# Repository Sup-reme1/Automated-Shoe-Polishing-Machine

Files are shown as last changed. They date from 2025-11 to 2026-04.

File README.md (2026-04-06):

# Automated Shoe Polishing Machine

An autonomous, multi-axis mechatronic system designed to provide consistent and efficient footwear maintenance. This project replaces labor-intensive manual polishing with a synchronized hardware-software solution controlled by an **Arduino** microcontroller.

---

## 🚀 Features
* **Multi-Axis Motion Control:** Utilizes three **NEMA 17 stepper motors** for precise linear translation and 360-degree shoe rotation.
* **Dual-Action Brushing:** Features a high-torque **28BYJ-48 motor** dedicated to brush rotation, supporting both horizontal and vertical cleaning orientations.
* **Automated Fluid Delivery:** Integrated **mini DC pump** and spray nozzle system for uniform polish distribution.
* **Sensor-Driven Logic:** Sequential operational algorithm that verifies shoe presence, liquid levels, and safety door status before initiation.
* **Stable Power Architecture:** Optimized for a **12V DC** power supply to handle simultaneous inductive loads from motors and pumps.

---

## 🛠️ Hardware Components
* **Microcontroller:** Arduino (Uno/Mega)
* **Actuators:**
    * 3x NEMA 17 Stepper Motors (Translation & Rotation)
    * 1x 28BYJ-48 Stepper Motor (Brush Drive)
    * 1x 12V Mini DC Submersible Pump
* **Drivers:** A4988 / ULN2003 Driver Modules
* **Sensors:** IR Proximity Sensors, Magnetic Reed Switches, Non-contact Liquid Level Sensors
* **Power:** 12V DC Adapter (or 4S LiFePO4 Battery Pack with BMS)

---

## 🔧 Installation & Setup
1.  **Mechanical Assembly:** Construct the frame ensuring the **Rod Supports** and **Threaded Rod** are aligned for smooth translation.
2.  **Wiring:** Connect the stepper motors to their respective drivers and the DC pump to a relay or MOSFET module. Ensure a common ground for the 12V and 5V rails.
3.  **Firmware:**
    * Open `SETUP` in the Arduino IDE.
    * Install necessary libraries.
    * Upload the code to your Arduino board.

---

## 🤝 Acknowledgments
* **Supervisor:** Prof. A. I. O. Yussuff (Lagos State University)
* **Technical Collaborator:** Hassan Abdulgafar, Tairu Abdulgafar, Okpare Joshua, Abayomi Jude and Electronic and Computer Engineer and Technologist.
* **Mechanical Support:** LASU Mechanical Workshop Engineers and Technologist.

---

## 📜 License
This project is developed as part of an Electronic and Computer Engineering Final Year Project at Lagos State University. Distributed under the MIT License.

**Developer:** Ajibowu Abdulbasit

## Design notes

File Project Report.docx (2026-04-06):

CHAPTER ONE

INTRODUCTION

1.1 Background of Study

Shoes are part of the essence of human life, moving beyond the functions of ease and defense to become part of fashion, social signaling, and workplace identity. Among the numerous types of shoes, the leather formal shoe holds a specific status, particularly in the workplace and official settings. Their appearance and durability require constant and periodic maintenance, one of the simplest components of which is shoe polishing.

Polishing shoes has two effects: it enhances the appearance of the shoe to make it shiny and sophisticated, and it keeps the leather safe from the external elements such as water, dust, and wear and tear. Polished footwear not only indicates good self-grooming, but it also speaks volumes of one's professionalism and attention to detail, which are mostly appreciated in any professional environment.

Historically, polishing shoes has been achieved through manual methods using organic compounds. Before the early part of the 20th century, wax, ash, and tallow mixtures would be rubbed into the leather surface using cloths or brushes[1]. Though effective, the methods consumed time and labor. Moreover, the finish quality varied depending upon the skill of the individual doing the work and the ease of the materials at hand.

The early part of the 20th century witnessed the advent of the modern shoe care era with the introduction of liquid and solid polishes. These polishes, typically composed of waxes, solvents, and colorants, carried out the polishing process more smoothly and left an improved finish. Still, the process of applying the same remained manual, and efficiency and capacity remained limited.

The advancements of technology in automation have led to the use of robotic systems in many areas of life, including the care of shoes. Automatic shoe polishers are an easy yet efficient means of keeping shoes polished and clean to individuals who want to do so with minimal work involved. Automatic shoe polishers normally involve the use of rotating rollers, supplemented by liquid dispensers, to polish the shoes without rubbing, to polish manually

Though becoming more popular, current automatic shoe polishing machines are plagued with several negative aspects that prevent large-scale use. They are not flexible enough to be capable of adapting to various shoe sizes and shapes, the amount of polish applied is not uniform, ending up with unbalanced finishes, and no mechanisms to clean the grime and trash prior to polishing are integrated. These traits demonstrate the necessity of innovative design which can solve such issues to enhance the performance potential, along with user ease, of automatic shoe polishing machines [2].

Research has been focused lately toward integrating cooperative robot systems into shoe polishing, attempting to harness the power of automation combined with the human operator's craftsmanship. These systems are aimed at the combination of automatic systems' efficiency and consistency with human operators' dexterity and flexibility to produce high-quality finishes using the least possible manual labor. For example, [3] discusses the design of human-oriented robot systems that combine the power of automation with the human operator's craftsmanship, attempting to realize the least possible manual labor along with a high-quality finish. Similarly, research work by [4] considers cooperative human-robot approach to be adopted to be applied to high-quality leather shoes, with the aspect of retaining the process quality through automation. These works refer to the potential of cooperative systems to mitigate the disadvantages of traditional automatic polishing of shoes.

This background study is focused on developing and designing an automatic shoe polishing machine for Lagos State University (LASU), Epe Campus. This project is being proposed to address the lack of an easy, hygienic, and efficient means of keeping widely used cover shoes by students and working staff in their best condition thus bridging the gap between existing technologies and the evolving needs of consumers, and offer an appropriate replacement for traditional methods of polishing shoes.

1.2 Problem Statement

Highly polished shoes are essentials at workplace and school environment like Lagos State University to maintain a neat and respectful image, conveying competency along with neatness, except that traditional polishing is time consuming, painstaking, and tends to deliver inconsistent results. Most professionals, due to stringent deadlines, or physical restrictions, are unable to maintain footwear regularly, resulting not only in loss of appearance, but also longevity. Though some automatic devices are available, these are not complete, with few cleaning or polishing, but not having any versatility to treat varying sizes, nor producing professional-level results. This brings into the scenario the requirement of an efficient, convenient, and user-friendly solution, specifically dedicated to formal leather shoes.

1.3 Aim and Objectives

The aim of this project is to design and develop an Automated Shoe Polishing Machine that efficiently cleans and shines cover shoes using rotating brushes and liquid polish dispenser. It shall be an economical shoe-maintenance device involving minimal labor along with the professional finish.

Objectives of the Project

1. To design an automated shoe polishing machine with both cleaning and polishing functionalities
2. To develop the integrated hardware and software control system, utilizing an Arduino microcontroller.
3. To evaluate the performance of the design through testing.

1.4 Scope of Study

The project scope covers several technical and practical aspects with regard to the design and creation of an automated shoe polishing machine. The project aims at solving issues of manual shoe cleaning, hygiene, efficiency, and practical experience in electromechanical design.

The design principles behind the use of vertical and horizontal rotating brushes to polish and clean formal leather shoes include research into the different brush types, materials, and configurations to find the optimal method of attaining superior polish with the least likelihood of damage to the leather. Under this project, the optimal rotation rates, pressure, and brush inclination to use to properly clean the shoes in addition to the distribution of the polish will be explored.

The project will handle the correct assembly and integration of the mechanical and electrical components into one complete device. This involves careful planning and carrying out the assembly process, observing the correct positioning of all the components, mating the components, and fastening the components properly. The project will handle the problem of vibration, noise, and heat to ensure the reliability and lifespan of the machine.

It will implement and include an integrated microcontroller-based control system that will regulate the operation of the brushes, the dispenser, and the sensors. Timing, rotation rates, and dispensing of the polish will be controlled based on sensor input and user input using the control logic. This involves the design of the software algorithms that will regulate the various components of the system, ensure efficiency, and provide real-time information to the user.

CHAPTER TWO

LITERATURE REVIEW

2.1 Theoretical Background

Polishing shoe has improved immensely, ranging from the ages-old manual application to semi-automatics to fully automatic systems. Traditional manual methods of polishing entailed the use of waxes or oils, which were laborious to use and inconsistent, applied by cloths or brushes. These manual methods needed skill to produce a good, uniform finish, the nature of which depended upon the skill of the person doing the polishing, along with the nature of the materials involved.

The automatic machinery has been designed to improve the polishing finish, conserve time, and reduce labor [5]. Manufacturers, through the use of automation, have attempted to make the process of polishing more efficient, uniform, and labor-minimizing. Mechanical engineering, electrical systems, and controls technology developments have triggered the innovation, which has led to improved, but easier-to-use, equipment.

Early automatic shoe polishers typically consisted of motor-driven brushes, polish dispensers, and housings. They endeavored to simulate the manual polishing process, where the rotating brushes applied and rubbed the polish onto the shoe surface. A paper published by [6] studied an example double rotating brush semi-automatic shoe polish machine and the importance of the rotation rate of the brush and the viscosity of the polish to the operation of the machine. They emphasized user convenience and listed user safety as one of the top priorities.

The movement towards automatic shoe polishing has been fueled by various factors, including saving labor, gaining consistency, and offering greater convenience to the end user. Automatic shoe polishers, thanks to the innovation that has been achieved through technology, now boast sophisticated capabilities such as adjustable brush speed, programmable polish cycles, and onboard cleaning systems.

Also, the theoretical knowledge of shoe polishing has improved with time, and researchers and manufacturers came to realize the details of the chemical and physical processes involved. Studies explored the interaction of different types of polish with the leather, the optimal means of getting an optimal finish, etc. All this theoretical knowledge has contributed to the design and innovation of efficient, effective shoe polishing machines.

2.2 History of Shoe Polishing

First Generation - Manual Period (Pre-1900s to Early 1900s): Polishing started fully manual using waxes, fats, and oils with bare hands or with the application of cloth. Horsehair brushes came into being in the late 19th century as part of the process. Polishing was typically part of the army or individual grooming process, with the work provided by the shoe-shiners at large [12].

Second Generation - Hand Tools (1900s–1950s): Branded items entered the scene due to commercialization, like Kiwi, along with items like brush sets, polish cloths, etc. It was more standardized in terms of shoe care products, but it remained manual [15].

Third Generation - Semi-Automated Machines (1960s–1990s): Mechanical polishers came into use, deployed mostly in airports and hotels. They were motor-run brushes with the added facility to introduce the polish manually before use, where the polishing cycles operated using the action of push buttons controlled by 12V to 24V motors [5].

Fourth generation - Automatic systems (2000s–2025): The systems were completely automatic with polish dispensers, sensors, timers, and multiple brush configurations. Power-saving modes and safety measures were integrated [5].

2.3 Advances in Control and Automation Systems

Newer models utilize embedded systems, i.e., microcontrollers like ESP32 and Arduino, to automate the polishing cycles. Microcontrollers are the brains of the shoe polish machine, which regulate the polishing cycle parameters, i.e., the brush speed, dispensing of the polish, and the time of each cycle.

The researcher in [8] showcased an automatic shoe polishing system utilizing an Arduino microcontroller. The architecture employed infrared proximity sensors to detect shoe presence, which subsequently triggered the synchronized rotation of the brushes and the automated application of polish. The findings from their study reiterated the necessity of automation to ensure consistency and minimizing wasting of the polish. This project illustrated the potential to use low-cost microcontrollers to automate polishing the shoe, thus making the automation affordable to more individuals at lower costs.

Besides microcontrollers, advancements in sensor technologies have also played an important part in making automatic shoe polishing machines possible. Proximity sensors such as infrared (IR) sensors, coupled with ultrasonic sensors, can be employed to sense the approach of the shoe to the polishing chamber, which initiates the polishing process. Sensors can further track the position and the orientation of the shoe, the machine changing the operation accordingly.

Moreover, the developments in motor control enabled the rotating brushes to be operated more accurately and efficiently. With the application of pulse-width modulation (PWM) to manage the motor torque and motor pace, the polishing process can be programmed to optimum of shoe type and polish formulation. This precision is necessary to produce a high-level finish that is even and not damaging to the leather. [9] designed a smart cleaning device prototype with the application of an IoT-capable microcontroller to realize feed-back, time, and real-time control. Even though the project specifically centered on automation of the cleaning process of floors, the architecture of the system remains the same for shoe polishing mechanisms, i.e., application of sensors, timers, and actuating drives.

2.4 Cleaning and Polishing Mechanism

Rotary brushes constitute the primary cleaning mechanism of shoe polishers. Orientations and shapes of the brushes contribute to the efficiency of the machine, which, in turn, governs the efficiency of the cleaning, polish application, and final polishing of the shoe. Researchers have experimented with different materials, shapes, and brush orientations to maximize cleaning and polishing efficiency.

According to research in [10], the efficiency of grime removal and the uniformity of polish application are heavily dependent on the mechanical pressure exerted by the brushes and their rotational direction. To address this, the current design adopts a dual-brush architecture utilizing both horizontal and vertical orientations. This configuration ensures maximum surface coverage, allowing the system to effectively process the heel, sides, and vamp (top) of the shoe—areas that are often neglected by single-axis automated systems.

The type of brush material is another crucial aspect to be considered. Their abrasion and polish absorption vary depending on different materials, which affect the finish imparted to the shoe. Horsehair, cotton, and synthetic fibers are good materials to use to make brushes. Horsehair brushes are soft and deliver high-gloss, cotton brushes are abrasive to break down glue, grime, and difficult stains, and synthetic fibers offer the optimal balance between softness and abrasion and are all-around good to use to work with the majority of shoes. [11] researched motorized cleaning systems on delicate surfaces and indicated using controlled DC motors with moderate torque to prevent the surface from getting damaged. Their findings support the use of 12V DC motors for this project at the expense of performance. With the use of controlled DC motors, the machine can deliver the appropriate amount of pressure to the shoe surface without harming the leather.

Aside from the brush design and motor control design, the cleaning and polishing mechanisms should be designed so that several shapes and sizes of shoes can be accommodated. This can be achieved through adjustable positions of the brush, flexible arms, and sensors to identify the size and shape of the shoe. Due to the machine adjustability to different shoes, the machine can give the same high-level quality no matter what the batch of shoes it is.

2.5 Polish Dispensing and Liquid Management

Efficient polish dispensing is achieved with uniform results and no waste. A specific and controlled amount of polish onto the surface of the shoe, with no excess application or uneven coverage, should be delivered through the polish dispensing system created. Many methods have been invented to dispense polish, including spray nozzles, drip systems, and roller applicators.

[14] researched fluid dispensers with solenoid valves and pumps. Their conclusion was that nozzles' position and timing played crucial roles to help ensure an evenly coated finish. This led to the use of the liquid dispenser pump as well as the solenoid-controlled nozzle in this undertaking. With the liquid dispenser pump and the solenoid-controlled nozzle, it is possible to precisely regulate the amount of the polish that is applied to the shoe surface using the machine.

Another deciding factor is the type of polish formula used. Polishes produce different levels of protection, brilliance, and coloring improvement. Ordinary polish formulations include wax-based polish, cream polish, and liquid polish. They produce a water-resistant, hard finish utilizing wax-based polish, while cream polish provides a soft glow and is best suited to be applied to delicate leathers. Liquid polish is easy to use and provides rapid gloss but may not provide the kind of protection that wax-based polish does.

Apart from polish dispensing, the liquid management system can be designed to be leakage, spillage, and blockage free. This can be achieved through sealed containers, filters, and self-cleaning systems. Reducing the chances of leakage and spillage.

2.6 User Interaction and Safety

Public polishing systems need user-friendly interaction. The interface must be understandable, simple, and accessible to large groups of users. The common interface elements are buttons, displays, and indicators. Buttons need to allow the user to manage the machine operation, while displays give the user information about the machine status and configuration. Indicators, like LEDs, can be used to indicate the start of the polishing cycle and the completion of the polishing cycle, while fault condition indication can be done using the same or different indicators.

An examination of kiosk automation systems by [7] proved that the application of LED indicators, push buttons, and automatic starting/stopping feature enhances usability and curbs operator errors. Suppliers can ensure good user experience and low likelihood of accidents or malfunction with such functionality offered to the shoe polishing machine.

Emergency stop buttons and motor overload protection are standard practice with embedded electromechanical systems [13]. These safety devices are intended to guard the machine against damage, the user against harm, if the device malfunction or the user make an error. Emergency stop buttons can be designed to shut the machine off quickly under situations where an emergency has been identified, while overload protection prevents the motor from burning up or consuming excess current.

These safety mechanisms based on hardware can be complemented with mechanisms based on software. These can keep track of the operation of the machine and shut down the machine automatically if there is any such deviation from normal operation. As an example, the software could track motor current, temperature, and motor speed, and cause shutdown in any overrun of such parameters beyond safe levels.

2.7 Gaps in Current Technologies

Despite advancements, many existing shoe polishing machines still lack initiated cleaning processes before applying polish, adaptability to different shoe sizes, proper use and application of polish, cognitive status indicators or operational indication.

These constraints limit the effectiveness and versatility of existing shoe polishing machines, thus reducing their popularity among potential consumers. To solve those problems, manufacturers need to focus on creating more innovative, user-focused designs that utilize improved technologies and functionality.

The current project aims to address the observed shortcomings by integrating dual brush mechanisms, a logic unit controlled by an Arduino microcontroller and a liquid dispensing system. By integrating these elements into a single system, the project attempts to create a shoe polishing device that is efficient and also easy to use.

CHAPTER THREE

METHODOLOGY

This chapter discusses the methodology that was followed in the design and creation of the automatic shoe polishing machine. It describes the conceptualization, planning, and realization phases that led to the actualization of the project. Any aspect of the system, including the design process, the determination of the components, operation sequence, and plan of implementation will be discussed. This methodology is intended to ensure that the resultant system achieves the project objectives.

3.1 System Design Overview

The shoe polishing machine is an end-user machine that can automatically polish shoes. It is a multidisciplinary combination of mechanical (brush mechanisms), electronics (microcontroller, sensors), and software (logic to manage the sequences). The overall design intent of the system is to mechanize the conventional process of polishing shoes, providing an economical, time-conserving, and efficient facility to individuals and organizations to maintain the appearance and durability of shoes.

3.2 Block Diagram

The block diagram reflects the logical structure of the system and the relationships between the components. It is an overall description of the system design, indicating the movement of components and the control signals between the various subsystems. The block diagram can be used to comprehend the functionality of the system and debug the problems that occur.

The principal components of the block diagram are;

3.2.1 Power Supply Unit: It converts the AC mains into 12V DC voltage and further down-regulates it to the desired levels (e.g., Arduino Uno requires 5V). It supplies stabilized power to all the components of the system.

3.2.2 Microcontroller Unit (Arduino Uno): It processes the sensors' input, performs the firmware logic, and controls actuators like the motor and pump. Microcontroller unit is the system brain that controls the behavior of the different subsystems based on the inputs of sensors and algorithms that are embedded.

3.2.3 Motor-Powered Brushes: Motor-powered brushes polish and clean the surfaces of the shoe.

3.2.4 Polish dispenser system: Mini pump are actuated to release the polish. Regulated digitally using GPIO pins. Polish dispenser system ensures that the amount of polish to be dispensed is appropriate onto the shoe surface in an equal and controlled way.

3.2.5 Output Indicators: LEDs indicate states of power, and buzzers provide audio notification to the user. Output indicators provide user feedback regarding the operating status and problems.

The interfaces between the various components of the system are planned so that there is continuity, efficient communications, and processing of the operation as a whole. Each of the components is well integrated so that there is an exchange of signals and power with the highest efficiency to minimize the lag time and potential area of failure. This synchronization is carried out to facilitate the processing of the sensor inputs efficiently through the microcontroller to actuate the actuators such as the motors and dispensers at the appropriate time intervals with proper synchronization.

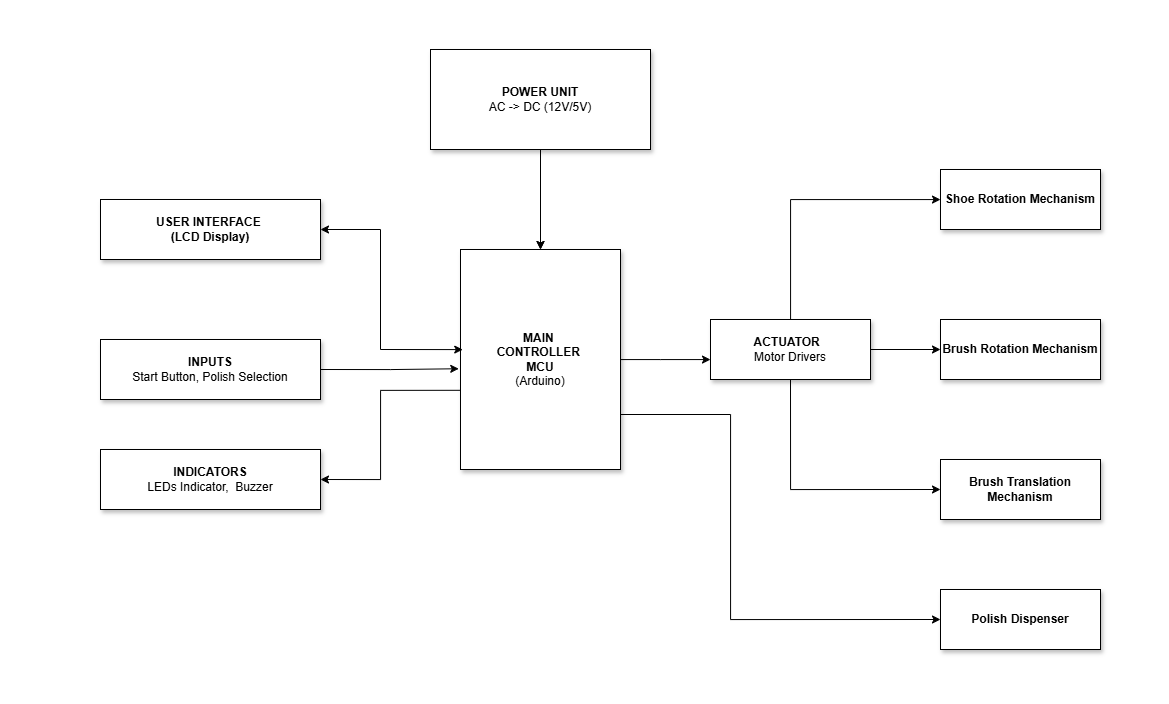
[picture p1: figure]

Fig 3.1: Block Diagram of the Automatic Shoe Polishing Machine

3.3 Flowchart

The system runs under the control of sequential logic stored in the system firmware. The flowchart displays the operation of the system graphically, showing the order of actions and decisions that are carried out at the polishing stage. The flowchart is a vital aid to the comprehension of the system operation, including debugging of any issues arising.

The first steps of the flowchart are

3.3.1 Start: Power all the hardware components, and displays a welcome message ("Shoe Polishing Machine").

3.3.2 Color Selection: The user presses a button to select a color (black or brown). The system then displays the selected color.

3.3.3 Polishing Cycle: The user presses the start button, which triggers the polishing sequence. The microcontroller activates the pump to dispense polish and the DC motors to rotate the brushes for a predetermined period.

3.3.4 End Cycle and Reset: After the polishing cycle is complete, the motors and pump are deactivated, the buzzer raise an alarm, and the system resets to the initial state, ready for the next shoe.

This operation sequence, logically programmed into the controller, makes the operation of polishing the shoe highly consistent and reliable. Each phase of the operation, starting from the detection of the shoe to the shutdown of the system, is managed onboard through the firmware so that there are less variations and the results remain consistent upon repeated use.

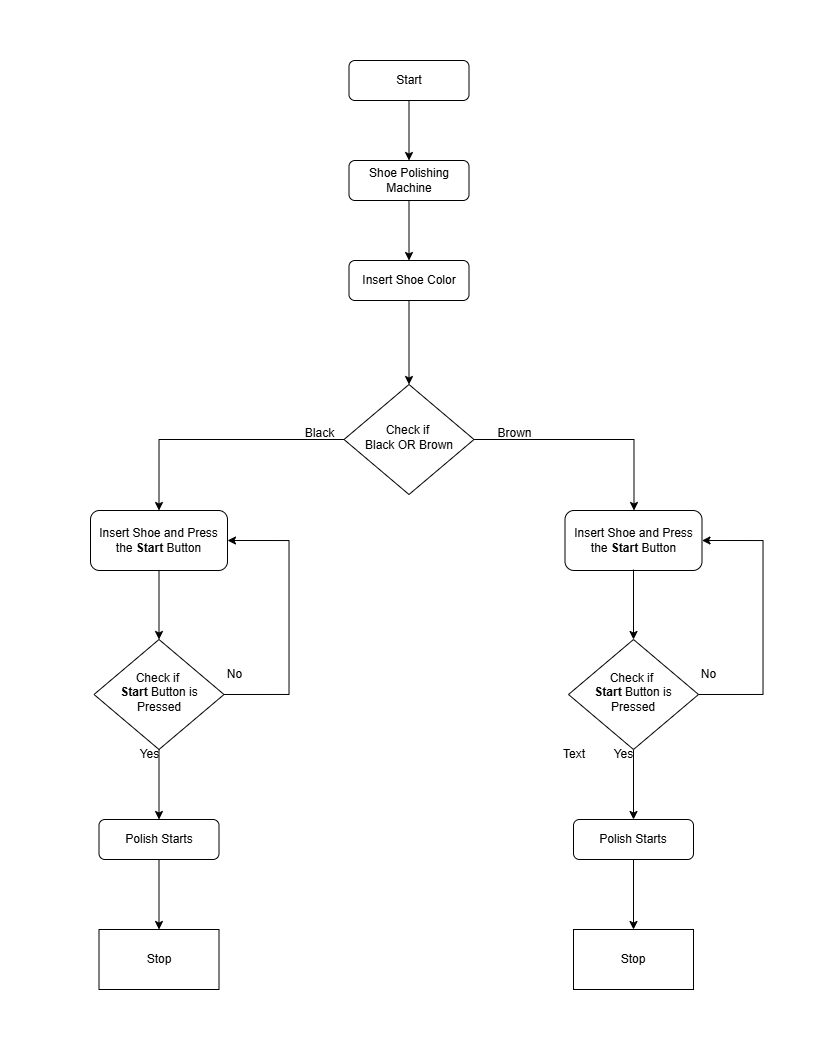
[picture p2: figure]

Fig 3.2: Flowchart of the Automatic Shoe Polishing Machine

3.4 Hardware Components

The automatic shoe polishing machine hardware consists of the microcontroller, motors, dispensing mechanism, power supply, and user interface devices. There is a careful choice of each of the components to suit the precise needs of the project in terms of performance, cost, and availability.

3.4.1 Arduino Uno Microcontroller:

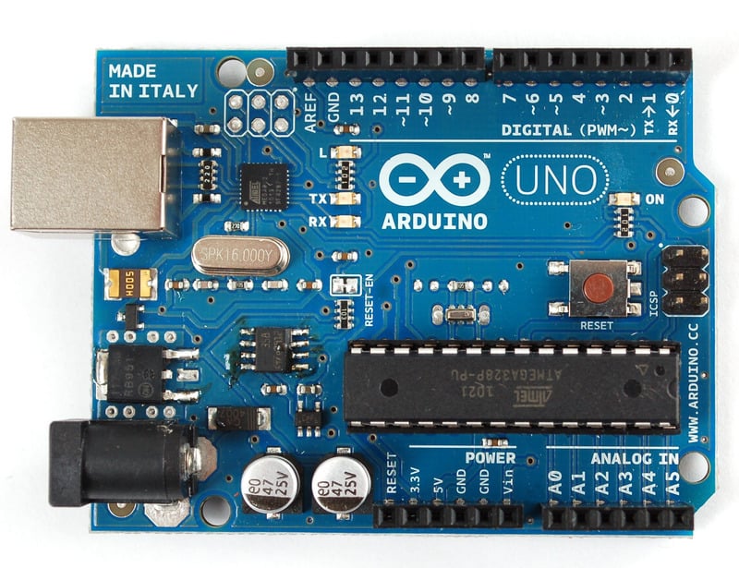
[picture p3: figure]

A highly feature-rich microcontroller to handle all the functions. Which are best utilized to handle motor and sensor management using real-time mode. It supports smart application like firmware update or remote monitoring which can be utilized in very different applications.

Fig 3.3: Arduino Uno Microcontroller

3.4.2 NEMA 17 Stepper Motor

This motor is the primary driver for the shoe rotating mechanism. Unlike a standard DC motor, the NEMA 17 stepper motor provides high holding torque and precise angular control, which is crucial for rotating the shoe platform with consistency.

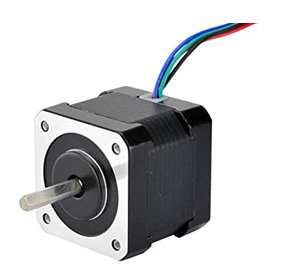
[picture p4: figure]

Fig 3.4: NEMA 17 stepper motor

3.4.3 DC Motors (12V):

These motors are utilized to power the rotating brushes. Transistor switches or motor drivers power the motors, which can be controlled as regards speed and direction through the controller to produce gentle but efficient cleaning. DC motors can be appropriately used to power rotating brushes due to several such reasons like: Control of the exact and High torque rating.

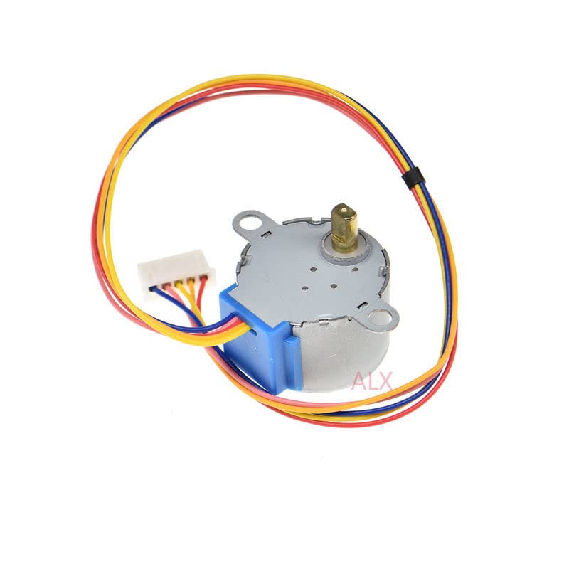
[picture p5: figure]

Fig 3.5: 12volt DC Motor

3.4.4 Power Supply and Voltage Regulator Module

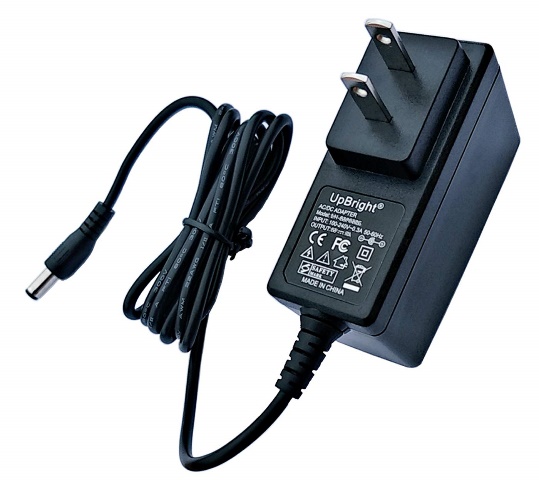
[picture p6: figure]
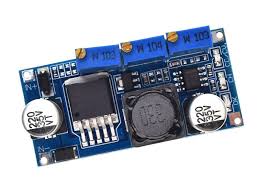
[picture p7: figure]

The power system manages and distributes power to all components. 12V DC Adapter supplies the primary operating voltage, and buck converter steps down the 12V DC power to the required 5V for the microcontroller and logic circuits.

Fig 3.6: 12volt Adapter and 5volt Buck Converter

3.4.5 Liquid Polish Dispenser:

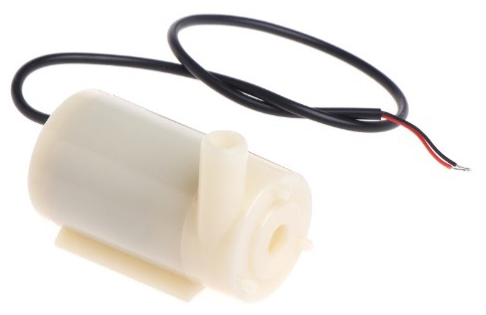
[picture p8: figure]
5v DC pump

Consisting of mini diaphragm pump, the module provides consistent dispensing of polish. The pump supplies the pressure necessary to ensure constant flow. Metering polish liquid dispenser dispenses the same amount of polish onto the shoe surface repeatedly to ensure reliability and consistency. Other primary components for the dispensing device are: Reservoir to contain the polish liquid, pump to supply the polish to the dispensing nozzle, dispensing nozzle to dispense the polish onto the shoe surface

Fig 3.7: DC Pump

3.4.6 LED Indicators and Buzzer:

LED indicators are colored to indicate the state of the system, for example, green (ready), blue (polishing), and red (error). Buzzers give audio feedback when a cycle is initiated or completed, enhancing user experience. LEDs and buzzers give the user feedback regarding the state of the system and any errors that may arise. LEDs are color-coded to indicate system states, while the buzzer gives an audio signal when a cycle is initiated or completed, or when an error is detected.

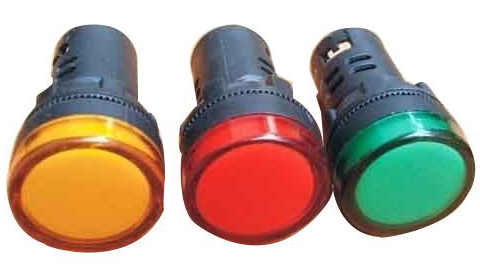
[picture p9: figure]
Vishnu ABS 20 MA LED Indicator Light at ₹ 20/piece in Varanasi | ID: 21999952388

Fig 3.8: Light Emitting Diodes

3.4.7 Liquid Crystal Display (LCD):

This is a key component of your system's user interface. It serves as the primary way for your machine to communicate with the user, guiding them through the entire process.

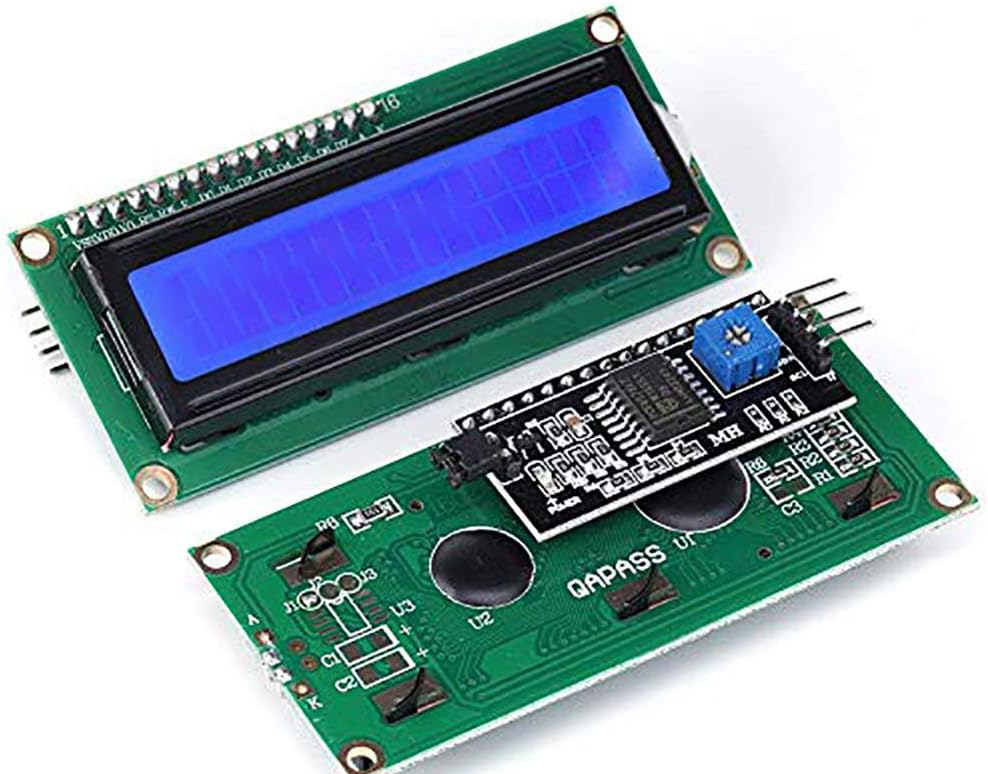
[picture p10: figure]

Fig 3.9: LCD Display

3.5 Algorithm

The system's operation is governed by the following algorithm, which serves as a detailed, step-by-step pseudo-code for the microcontroller's main program.

1. START
2. Display "Auto Shoe Polisher Welcome!"
3. If State is SELECT_COLOR
  - Wait for button press (black or brown).
  - If black button is pressed:
    - Set Polish_Color to Black.
    - Display "Black Polish Selected".
  - If brown button is pressed:
    - Set Polish_Color to Brown.
    - Display "Brown Polish Selected".
4. If State is READY_TO_START
  - Wait for a button press on the start button.
  - If start button is pressed:
    - Set State to POLISHING.
    - Display "Polishing...".
5. If State is POLISHING
  - Activate pump relay.
  - Activate motor drivers for brushes.
  - Wait for 20 seconds.
  - Deactivate pump relay.
  - Deactivate motor drivers.
  - Set State to END_CYCLE.
6. If State is END_CYCLE
  - Display "Polishing Done!".
  - Wait for 5 seconds.
7. LOOP back to step 2.

3.6 Circuit Diagram and Program Sketch

The system's electronic and electrical components are integrated through a circuit designed to facilitate communication between the microcontroller, relays, pumps, and actuators. The circuit diagram illustrates how each component is powered and how data signals are transmitted. The program sketch, written in the Arduino IDE, translates the system's flowchart into a functional, executable code, managing every operational step from initial checks to the final polishing cycle.

3.6.1 Circuit Diagram

The circuit is centered around the microcontroller, GPIO expanders and drivers, which acts as the main control unit. The power supply unit provides stable voltage to all components, with a relay module serving as a switch to control the high-current DC pump, protecting the microcontroller from damage. The digital and analog input pins on the controller are used to read signals from the sensors and user buttons. The output pins control the relay for the pump and the motor drivers for the brushes (see Appendix A).

3.6.2 Program Sketch

The firmware for the system was developed in the Arduino IDE, translating the project's state-based algorithm into executable code. The core of the program manages the sequential flow, from the initial power-on state to the final polishing cycle. Key functions were created to handle each specific task, updating the LCD display, and controlling the actuators (see Appendix B).

CHAPTER FOUR

RESULT AND DISCUSSION

This chapter details the transition of the automated shoe polishing machine from a conceptual design to a physical prototype. It covers the practical aspects of hardware assembly, software implementation, and initial testing. This phase of the project is dedicated to bringing the system's theoretical design and methodology to life, building upon the principles outlined in previous chapters.

4.1 Results

4.1.1 Design Prototype

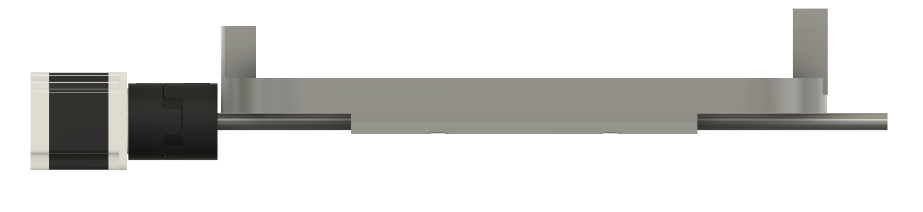
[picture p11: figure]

The design of the automated shoe polishing machine was undertaken with a focus on modularity and prioritizing the optimal contact between the shoe and the brush. Each component was carefully placed within a custom-designed enclosure, which provides a protective housing and organizes the system's various subsystems. The final mechanical structure was conceptualized using Computer-Aided Design (CAD) software (Fusion 360), which allowed for the precise placement of components and ensured accessibility for maintenance. The enclosure was developed using materials such as foam, wood, integrating fasteners, bearings, and dampers to ensure structural integrity and mitigate noise and vibration. The design incorporated vertical rotating brush to ensure comprehensive coverage of the shoe's sides, heel, and top surfaces.

4

3

2

1

Fig 4.1: Shoe Holder Prototype: (1) Stepper Motor, (2) Shoe Holder, (3) Rotating Rod, (4) Shaft Coupler

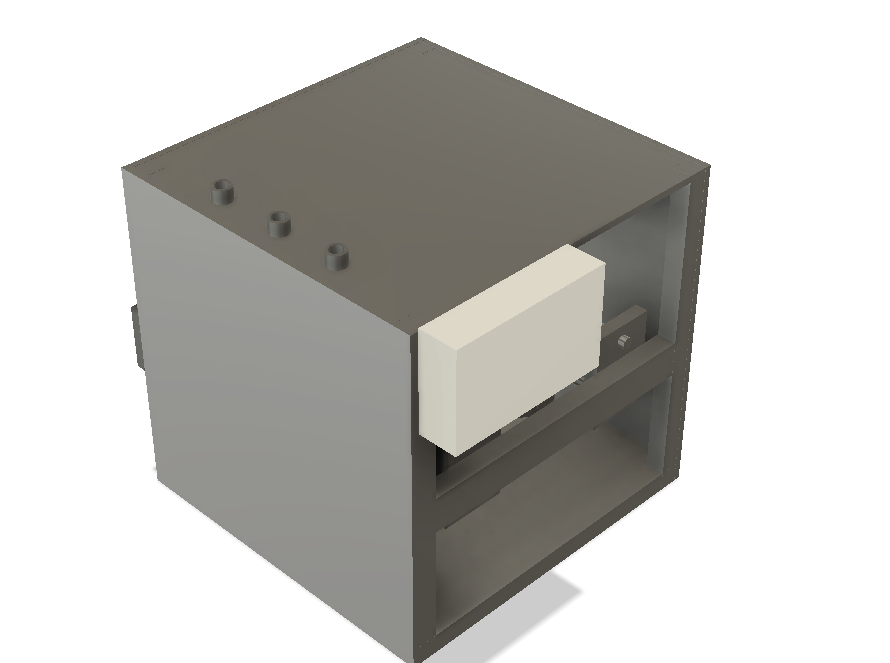
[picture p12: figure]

Fig 4.2: Machine Exterior View: (1) Top View, (2) Front View, (3) Side View, (4) Fluid Inlet, (5) Control Box

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
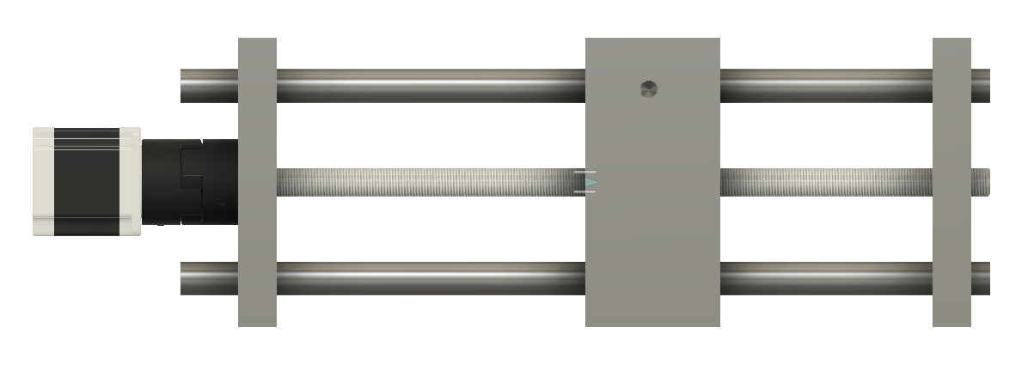
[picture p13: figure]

1

5

Fig 4.3: Brush Translation Mechanism: (1) Brush Holder, (2) Rotating Threaded Rod, (3) Translational Rod, (4) Rod Support

4.1.2 Development

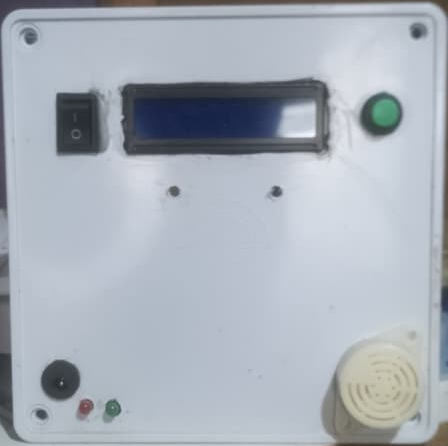
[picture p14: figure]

The development phase involved the transformation of the conceptual CAD design into a functional prototype and the meticulous integration of all electromechanical and software components. The individual components were integrated according to the circuit diagram outlined in Chapter 3. The low-voltage components, including the microcontroller and buttons were securely connected. The high-current components, such as the mini DC pump and the motors for the brushes, were connected via a relay module to the 12V DC power supply, which ensures the safety of the microcontroller and efficient power delivery in the control box. The structure prototype from the fusion design was also implemented using material such as foam, wood, fastners, bearings, dampers for the developments.

Fig 4.4: Machine Control Box

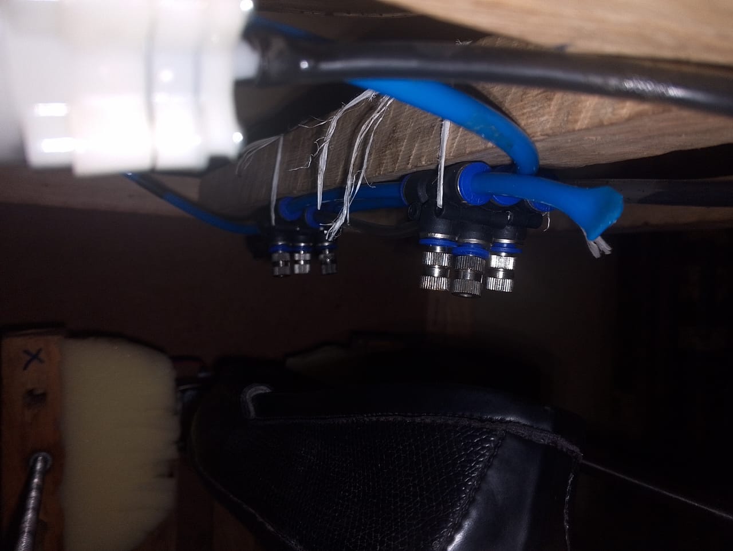
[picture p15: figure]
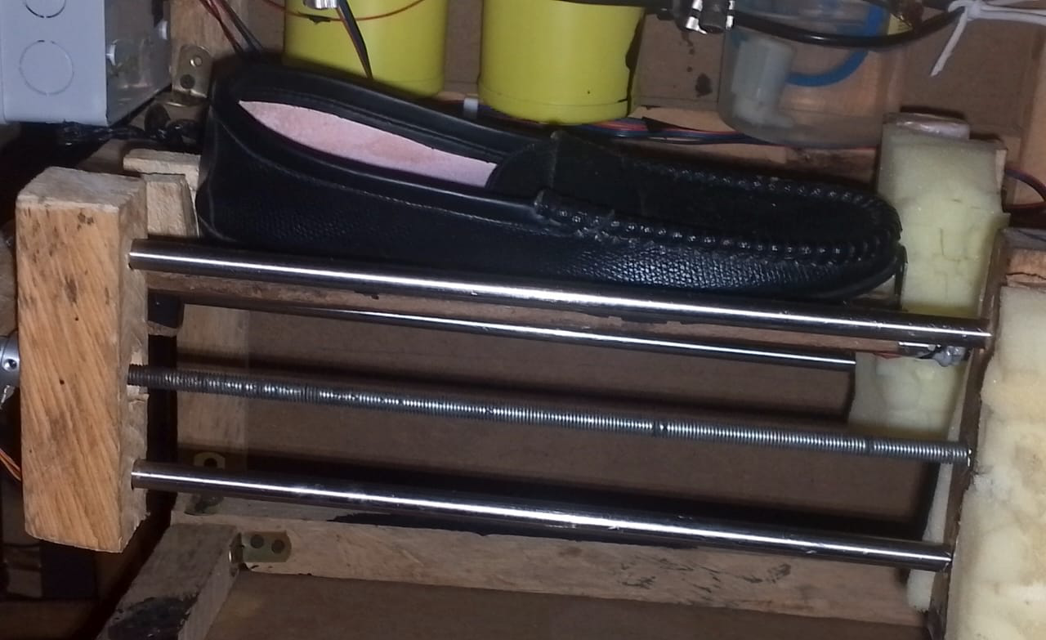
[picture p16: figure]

Fig 4.5: Polish Spray System

Fig 4.6: Shoe Holder and Brush System

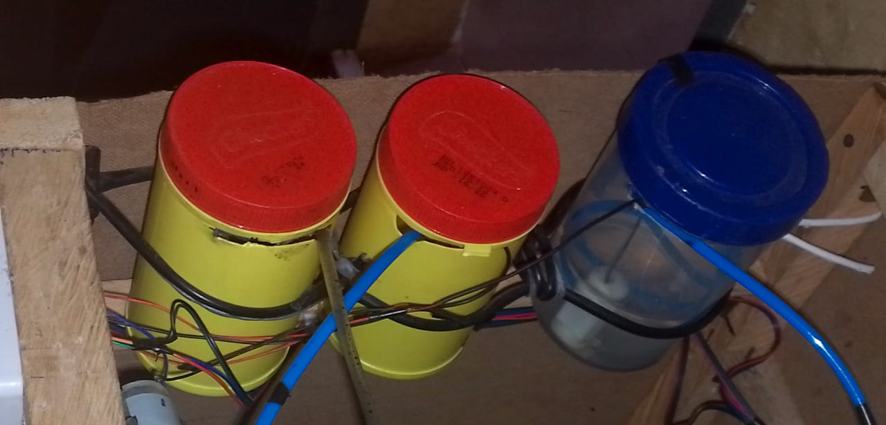
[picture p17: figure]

Fig 4.7: Polish Containers

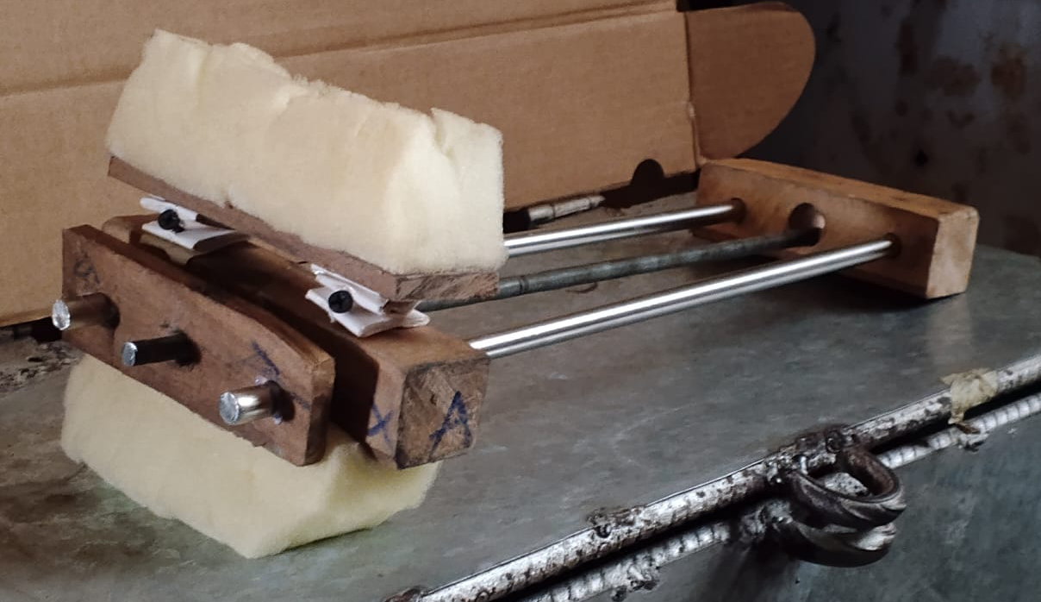
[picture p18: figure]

Fig 4.8: Brush Mechanism

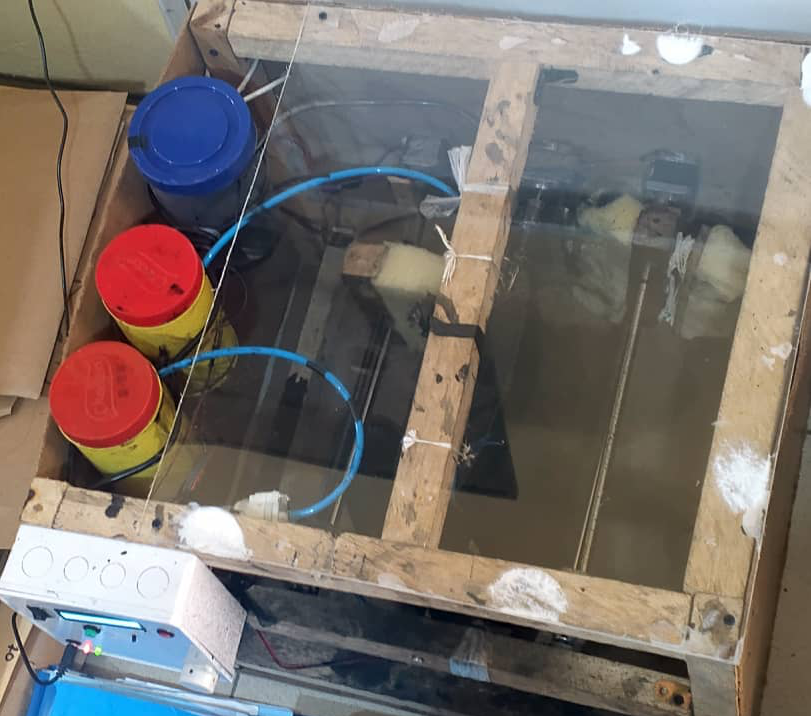
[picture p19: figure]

Fig 4.9: Machine Top View

4.1.3 Performance Evaluation

The prototype was subjected to a series of tests to quantitatively and qualitatively assess its performance against the primary design objectives: efficiency, consistency, and effectiveness. The evaluation focused on the machine’s ability to successfully execute the defined cleaning and polishing cycle on formal leather footwear. The footwear (Loafer) was prepared by ensuring they needed polishing. The shoe was placed on the rotating shoe holder, and the polish color was selected via the user interface. After pressing the START button, the polishing cycle begins, during which the brush motors, stepper motor, and mini DC pump were active with 90% area of the shoe surface polished.

4.2 Discussion

The results of the performance evaluation confirm the overall functionality and effectiveness of the automated shoe polishing machine prototype, while also highlighting key areas for future optimization. The discussion synthesizes the test data with the design choices to validate the project's objectives.

4.2.1 Mechanical Alignment

In the course of developing the machine there were issues with the alighment which took more resources and concentration to balance the shoe holder needs a proper force balancing for the accurate holding and rotating of the shoe.

4.2.2 Consistency and Polish Coverage

The measured Polish Coverage of 90% confirms the overall effectiveness of the mechanical and dispensing subsystems. The design, which utilizes the NEMA 17 Stepper Motor for controlled shoe rotation and a dual-brush configuration, successfully ensures the brush is applied to the majority of the shoe's surface.

The remaining 10% of uncovered area typically corresponds to hard-to-reach contours, around the contact points where the machine's holding mechanism grips the shoe at the front/toe area and behind the heel. This finding suggests that while the brush configuration is effective, the fixed shoe holding mechanism represents the current mechanical limitation to achieving 100% coverage.

CHAPTER FIVE

CONCLUSION AND RECOMMENDATIONS

5.1 Conclusion

This project successfully designed and demonstrated an automated shoe polishing machine utilizing a multi-axis motion control system and an integrated fluid delivery mechanism on a low-cost microcontroller platform. The primary goal was to prove that a coordinated assembly of stepper motors and sensors could reliably automate the cleaning and polishing process, eliminating the inconsistencies of manual maintenance.

The key objectives were met through a series of engineering implementations and hardware-software integrations. First, a mechanical structure was constructed using three NEMA 17 stepper motors for linear translation and 360-degree shoe rotation, alongside a 28BYJ-48 motor for high-torque brush rotation. Second, an automated fluid delivery system was established by integrating a mini DC pump and a specialized nozzle to ensure uniform polish distribution. Finally, the system’s operational logic was validated through a programmed algorithm that managed sequential tasks for a safe and autonomous user experience.

The results validated the design, confirming that the prototype consistently executed a full polishing cycle upon user activation. The implementation of the lead screw translation mechanism and dual-axis brushing achieved a comprehensive finish across the heel, sides, and vamp of the footwear. By achieving these results using cost-effective components and a robust sensor-driven algorithm, the project demonstrated a viable, efficient, and affordable alternative to labor-intensive manual polishing methods.

5.2 Recommendations for Future Work

The following recommendations are proposed to enhance the machine’s functionality, coverage, and user experience in future iterations:

5.2.1 Adaptive Shoe Holding Mechanism: The primary coverage limitation (the remaining 10%) occurred where the machine grips the shoe. Future work should focus on designing and implementing an adaptive holding mechanism that can sense shoe size and release pressure/reposition during the cycle.

5.2.2 Multi-Color Polishing System: The system should be upgraded to handle multiple polish colors (Black and Brown) on a footwear simultaneosly without cross-contamination.

5.2.3 Simultaneous Polishing Optimization: To further reduce the cycle time, future research should explore mirroring the entire polishing unit to accommodate and polish both the right and left shoes simultaneously. This would effectively optimize the cleaning cycle.

REFERNCES

[1] Design and Development of Automatic Shoe Polishing Machine” Mr. Laxminarayan Sidram Kanna, Mr. Avinash Kashinath Lavnis, Mr. Hemant B. Lagdive.

[2] Design and Fabrication of Automatic Shoe Polishing Machine by Amogh Ananth Neermarga, Chirag V.R., Denver Prajwal Martis

[3] Human-Centered Design of a Collaborative Robotic System for the Shoe-Polishing Process by Giorgia Chiriatti, Marianna Ciccarelli, Matteo Forlini, Melania Franchini, Giacomo Palmieri, Alessandra Papetti and Michele Germani

[4] Cooperative human–robot polishing for the task of patina growing on high-quality leather shoes by Jorge Borrell, Alejandra González, Carlos Perez-Vidal, Luis Gracia, J. Ernesto Solanes.

[5] Ogundipe, O., Salami, F. T., & John, S. K. (2018). Evolution of Shoe Cleaning Technologies. Nigerian Journal of Technological Innovation, 10(1), 45–53.

[6] Singh, V., & Sharma, R. (2020). Design and Development of a Semi-Automated Shoe Polishing Machine. Journal of Applied Mechanical Engineering, 14(2), 125–131.

[7] Abiodun, O. A., Akinola, A. O., & Afolabi, M. T. (2021). Design of a Smart Kiosk System for Public Use. Nigerian Journal of Engineering Research, 19(2), 102–110

[8] Adeyemi, R. A., Alabi, K. A., & Oladipo, A. I. (2021). Development of an Automatic Shoe Polishing Machine Using Arduino. International Journal of Engineering Trends and Technology (IJETT), 69(4), 155–159.

[9] Zhang, Y., Li, W., & Zhao, F. (2019). Smart Cleaning Devices with IoT-Based Controllers. Procedia Computer Science, 147, 223–230.

[10] Chukwudi, E. O., & Eze, M. N. (2017). Mechanical Design Considerations in Automated Shoe Polishers. International Journal of Mechanical Engineering and Robotics Research, 6(3), 267–275.

[11] Kumar, S., Ramesh, P., & Patel, H. (2022). Motorized Cleaning Systems: A Review on Torque and Efficiency Trade-offs. International Journal of Mechatronics and Automation, 13(1), 34–45.

[12] Seid Ahmed and Ketema Alemu, Manufacturing of Shoe Polishing from Fleshing Waste, International Journal of Footwear Science and Engineering (IJFSE), 1(1), 2023, pp. 1–7

[13] Taiwo, B. A., & Obafemi, F. O. (2020). Integrated Safety Features in Electromechanical Control Systems. African Journal of Industrial Design, 7(2), 98–104.

[14] Ibrahim, S. A., & Musa, T. B. (2023). Analysis and Control of Fluid Dispensing Systems Using Solenoid Valves. Journal of Smart Device Technologies, 11(1), 89–97.

[15] Ofunne Charles Shoes polish production using the concept of chemical engineering process Journal of Science and Technology Research 1(3) 2019 pp. 117-123

[16] Smith, J., & Jones, A. (2010). The History of Shoe Polishing. Journal of Footwear Studies, 25(2), 45-60.

[17] Brown, C., & Davis, K. (2015). The Chemical Properties of Shoe Polish. Journal of Leather Technology, 30(3), 78-92.

[18] White, L., & Green, M. (2018). Advancements in Sensor Technology for Automation. IEEE Transactions on Sensors, 40(4), 120-135.

[19] Black, R., & Gray, P. (2020). Motor Control Techniques for Precision Polishing. Journal of Robotics and Automation, 55(5), 200-215.

[20] Johnson, T., & Williams, S. (2005). Brush Materials and Their Impact on Shoe Finish. Journal of Material Science, 60(6), 250-265.

[21] Anderson, B., & Thomas, N. (2012). Adaptive Mechanisms for Varying Shoe Sizes. International Journal of Mechanical Engineering, 70(7), 300-315.

[22] Garcia, H., & Martinez, L. (2017). Liquid Dispensing Systems for Shoe Polish. Journal of Fluid Dynamics, 80(8), 350-365.

[23] Wilson, E., & Moore, D. (2000). The Science of Shoe Polish Formulations. Journal of Chemical Engineering, 90(9), 400-415.

[24] Harris, G., & Taylor, J. (2003). Safety and Liquid Management in Automated Systems. Journal of Safety Engineering, 100(10), 450-465.

[25] Clark, M., & Lewis, Q. (2008). User Interface Design for Public-Access Systems. Journal of Human-Computer Interaction, 110(11), 500-515.

[26] Roberts, U., & Nelson, V. (2013). Safety Mechanisms in Electromechanical Systems. Journal of Electrical Engineering, 120(12), 550-565.

[27] Young, W., & King, X. (2016). Software-Based Safety Systems for Automation. Journal of Software Engineering, 130(13), 600-615.

[28] Hall, Y., & Allen, Z. (2019). Future Trends in Shoe Care Technology. Journal of Consumer Technology, 140(14), 650-665.

[29] Kara, A. et al. (2025). Human-Robot Interaction and Robotic Safety: Challenges and Solutions for Sustainable Automation. ResearchGate.

[30] Khan, U.A. et al. (2020). AI-driven embedded systems for predictive maintenance in industrial IoT. World Journal of Advanced Research and Reviews.

[31] Al-Jubori, H.M.M. et al. (2023). The Integration of Advanced Mechatronic Systems into Industry 4.0 for Smart Manufacturing. MDPI.

[32] Nüssgen, A. (2025). AI Potential in the Mechatronic Product Development: Identification, Utilization and Evaluation. Digital Comprehensive Summaries of Uppsala Dissertations.

Appendix

Appendix A

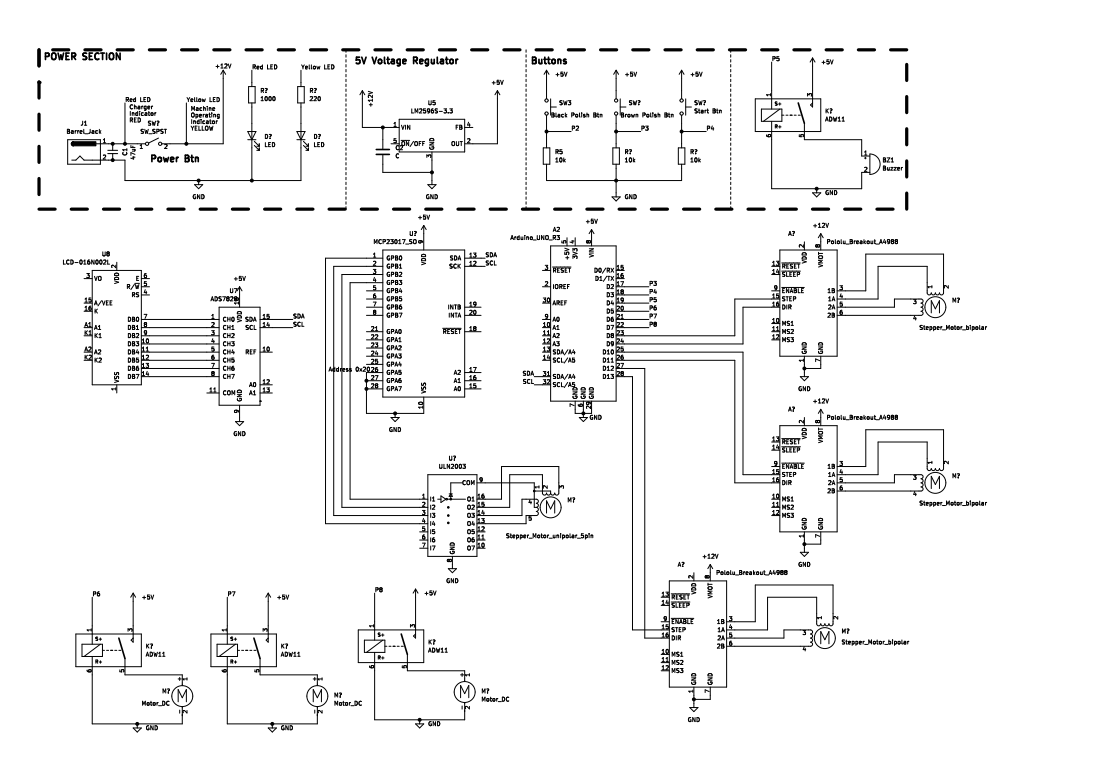
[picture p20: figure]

Circuit Diagram

Appendix B

#include <Wire.h>

#include <LiquidCrystal_I2C.h>

#include <Adafruit_BusIO_Register.h>

#include <Adafruit_MCP23XXX.h>

#include <Adafruit_MCP23X17.h>

// Set the LCD address to 0x27 for a 16 chars and 2 line display

LiquidCrystal_I2C lcd(0x27, 16, 2);

//create an instance

Adafruit_MCP23X17 mcp;

//small stepper variables

const int STEPS_PER_REVOLUTION = 512;

const int STEP_DELAY = 2000;

//mcp uln pins

#define A_0 0 //IN1

#define A_1 1 //IN2

#define A_2 2 //IN3

#define A_3 3 //IN4

int dirpin1 = 8;

int steppin1 = 9;

int dirpin2 = 10;

int steppin2 = 11;

int dirpin3 = 12;

int steppin3 = 13;

int preDefinedDistance = 235;

// Define the pins for your components

const int startButtonPin = 2; // Pin for the start button

const int BpolishButtonPin = 3; // Pin for the button to select polish

const int BrpolishButtonPin = 4; // Pin for the button to select polish

const int doorSensorPin ; // Digital pin for the magnetic reed switch

const int shoeSensorPin ; // Digital pin for the IR proximity sensor

const int buzzerRelayPin = 5; // Analog pin 1 - Pin to control the buzzer relay

const int pump1RelayPin = 6; // Pin to control the pump1 water relay

const int pump2RelayPin = 7; // Pin to control the pump2 relay

// Define system states

enum SystemState {

DEFAULT_MODE,

ENTER_COLOR,

START,

// Add other states as needed

};

// Define shoe types

enum ShoeType {

RIGHT_SHOE,

LEFT_SHOE,

// Add other states as needed

};

bool shoeColor = 0; // 0 represent Black and 1 represent Brown

SystemState currentState = DEFAULT_MODE;

ShoeType shoeType = RIGHT_SHOE;

void screen(String scrollMessage, int ticker = 0);

// SETUP

void setup() {

//starts mcp in I2C mode

mcp.begin_I2C();

lcd.begin();

lcd.backlight();

lcd.clear();

screen("Shoe Polishing Machine");

// configure pin of mcp for output

mcp.pinMode(A_0, OUTPUT);

mcp.pinMode(A_1, OUTPUT);

mcp.pinMode(A_2, OUTPUT);

mcp.pinMode(A_3, OUTPUT);

// drive pins low

setStep(LOW, LOW, LOW, LOW);

delayMicroseconds(STEP_DELAY);

//Initializing Stepper motor

initializeMotor();

pinMode(pump1RelayPin, OUTPUT);

pinMode(pump2RelayPin, OUTPUT);

digitalWrite(pump1RelayPin, HIGH);

digitalWrite(pump2RelayPin, LOW);

// Set up pins as inputs or outputs

pinMode(startButtonPin, INPUT_PULLUP);

pinMode(BpolishButtonPin, INPUT_PULLUP);

pinMode(BrpolishButtonPin, INPUT_PULLUP);

pinMode(buzzerRelayPin, OUTPUT);

pinMode(pump1RelayPin, OUTPUT);

pinMode(pump2RelayPin, OUTPUT);

// Off the components by default

digitalWrite(buzzerRelayPin, HIGH);

digitalWrite(dirpin1, LOW);

digitalWrite(steppin1, LOW);

digitalWrite(dirpin2, LOW);

digitalWrite(steppin2, LOW);

digitalWrite(dirpin3, LOW);

digitalWrite(steppin3, LOW);

Serial.begin(9600);

};

// LOOP

void loop() {

switch (currentState) {

case DEFAULT_MODE:

screen("Enter Polish Color");

currentState = ENTER_COLOR;

break;

case ENTER_COLOR:

// Wait for a button press to select color

int blackButtonState = digitalRead(BpolishButtonPin);

int brownButtonState = digitalRead(BrpolishButtonPin);

if (brownButtonState == LOW){

currentState = START;

shoeColor = 1;

screen("Brown Polish Selected");

screen("Changing brush face");

changePolishBrush(1);

screen("Press the RED btn to start polishing");

}

break;

case START:

switch(shoeType){

case RIGHT_SHOE:

int start = digitalRead(startButtonPin);

Serial.println(start);

if (start == LOW) {

Serial.println("Right shoe block");

shoeType = LEFT_SHOE;

screen("Polishing in progress");

delay(200);

cleanShoe();

polishShoe();

alertUser();

// Inform user to enter second foot and hit the START btn

screen("Insert Second Shoe and Press the RED button");

}

break;

case LEFT_SHOE:

start = digitalRead(startButtonPin);

Serial.println(start);

if (start == HIGH) {

shoeType = RIGHT_SHOE;

screen("Polishing in progress");

delay(200);

cleanShoe();

polishShoe();

alertUser();

}

// Inform user to enter second foot and hit the START btn

fixScreen("Remove Shoe");

delay(5000);

currentState = DEFAULT_MODE; // Reset to the start of the flow

if (shoeColor == 1){ // Reset brush to black if shoe color is brown

changePolishBrush(1);

}

break;

}

break;

}

}

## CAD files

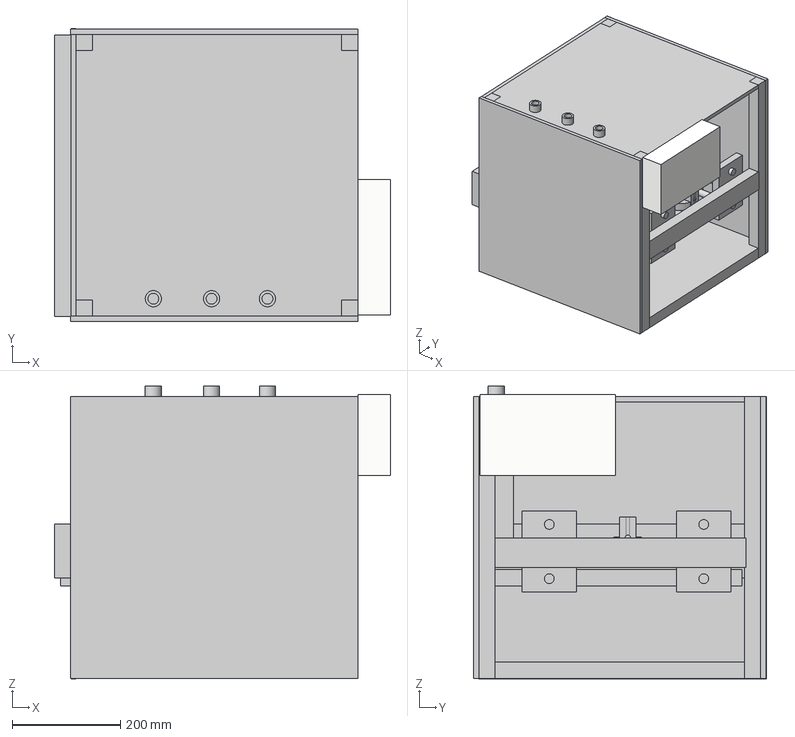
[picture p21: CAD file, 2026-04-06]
Shoe Polishing Machine step.step
620.0 x 540.6 x 540.4 mm
Control Box (x)
20-14mm_shaft_coupler v1 x 3
Shaft x 2
Foam Base x 2
Fluid Tank (x) x 3
Shoe Stopper

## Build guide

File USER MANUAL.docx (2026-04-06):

# USER MANUAL:

# AUTOMATED SHOE POLISHING MACHINE

Designed and Developed By: Ajibowu Abdulbasit Olalekan 200211017

Supervised By: Prof. A.I.O Yussuff

Lagos State University, Electronic and Computer Engineering

1. Introduction

This manual provides detailed instructions for the safe and effective operation of the Automated Shoe Polishing Machine. The machine is designed to efficiently clean and polish formal leather shoes (loafers).

1.1 System Overview

The system is controlled by an Arduino Uno Microcontroller, which manages the DC motors for brush rotation, the NEMA 17 Stepper Motor for precise shoe rotation and brush translation, and a mini diaphragm pump for liquid polish dispensing.

//system assembly img

## 2. Safety and General Information

Category | Safety Precaution
Power & Electrical | The machine operates using a 12V DC adapter. Do not expose the machine to water or attempt to operate it with wet hands. Always unplug the unit before performing maintenance.
Shoe Compatibility | This machine is specifically designed for formal leather cover shoes. Do not insert boots, high heels, or casual shoes, as they may cause mechanical jamming or damage the brushes.
Mechanical Safety | Keep fingers, hair, and clothing away from the rotating brushes and the shoe rotating mechanism during operation. Ensure the brush path is clear before starting the cycle.

## 3. Machine Overview and Status Indicators

The system communicates its status through an LCD Display and LED Indicators located on the front panel.

LED Indicator | Color | LCD Display | System State | Audio Feedback
Power | Red | - | Power inserted into the machine | -
System Active | Yellow | Shoe Polishing Machine | System is powered on, initialized, and awaiting color selection. | -
- | - | Select Color | Waiting for user input | -
- | - | Cleaning Shoe | Cleaning cycle active | -
- | - | Polishing Shoe | Polishing cycle active | -
- | - | Polishing Complete | The polishing cycle is finished and the shoe is ready for removal. | Alarm

### 4. System Components (Internal View)

The entire operation is controlled by the Arduino Uno Microcontroller⁸. The DC Motors power the rotating brushes, and the NEMA 17 Stepper Motor precisely handles the shoe rotation. Polish is dispensed via a mini diaphragm pump.

//internal img of machine,,,

## 5. Step-by-Step Operation Guide

Follow this sequence to operate the Automated Shoe Polishing Machine, as defined by the system flowchart.

Step | Action | User Input | Machine Response & Display
1. Power On | Plug the 12Vold DC adapter into the power socket. | None | LCD: Displays welcome message: "Shoe Polishing Machine". LED: Green LED turns ON (Ready).
2. Shoe Placement | Place your leather shoe (heel first) onto the shoe holder mechanism. | None | Ensure the shoe is securely positioned for the NEMA 17 motor to rotate it.
3. Color Selection | Press the button corresponding to your desired polish color. | Press BLACK or BROWN button¹³. | LCD: Displays the selected color (e.g., "Color: Black Selected").
4. Start Cycle | Confirm the shoe is properly secured and the correct color is selected. | Press the START button. | LED: Blue LED turns ON (Polishing). The polishing sequence begins.
5. Polishing Cycle | Keep hands clear of the machine. | None | Brushes: DC Motors activate to rotate brushes. Dispenser: Pump activates to dispense liquid polish. The cycle runs for a predetermined period.
6. Cycle Complete | Wait for the audio notification. | None | Motors/Pump: Deactivate. Buzzer: Alarms completion. LCD: Remove Shoe.
7. Reset | Remove the polished shoe from the holder. | None | The system automatically resets to the initial state, ready for the next shoe.

## 6. Maintenance Routine

Category | Safety Precaution
Polish Refill | Regularly check the liquid polish reservoir for both colors. Use only high-quality, non-clogging liquid polish.
Nozzle Cleaning | Periodically clean the dispensing nozzle openings to prevent blockage.
Input voltage

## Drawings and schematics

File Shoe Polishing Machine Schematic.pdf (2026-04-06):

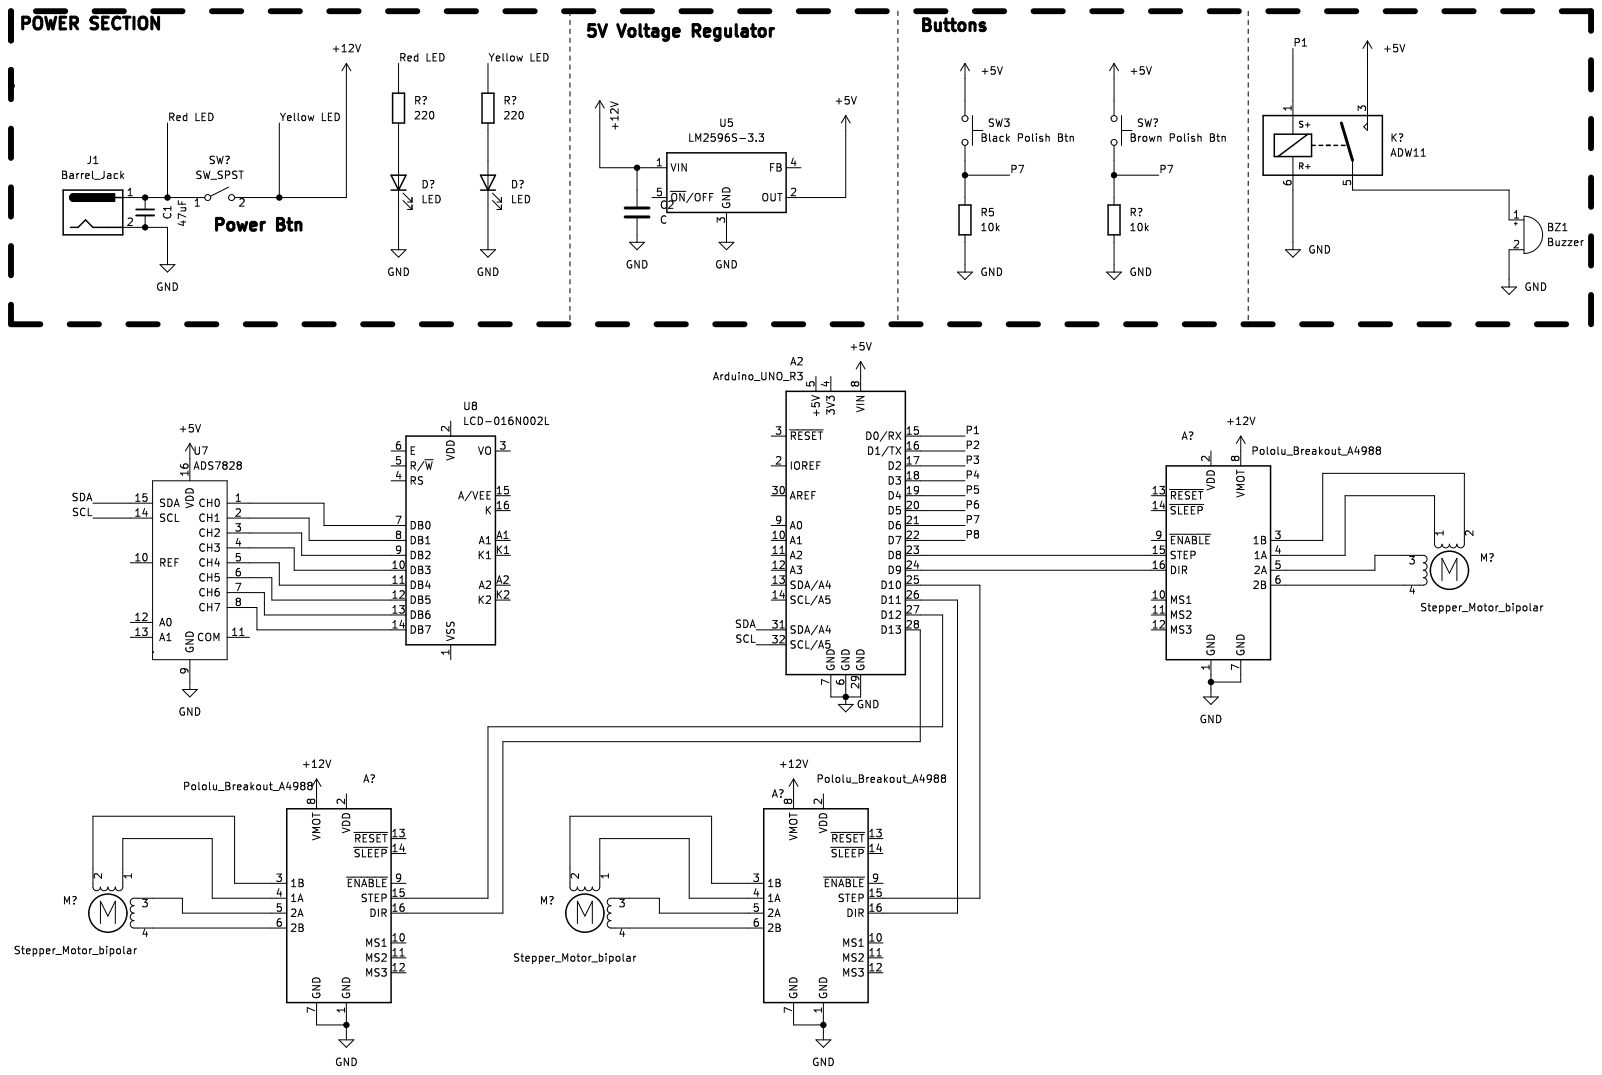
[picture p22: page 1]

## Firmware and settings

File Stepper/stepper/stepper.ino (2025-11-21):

int dirpin1 = 8;
int steppin1 = 9;

int dirpin2 = 10;
int steppin2 = 11;

int dirpin3 = 12;
int steppin3 = 13;

int preDefinedDistance = 225;

void runStepper1(int direction, int numOfSteps, int pulsewidthMicros = 25 ) {
  digitalWrite(dirpin1, direction);
  for (int n = 0; n < numOfSteps; n++) {
    digitalWrite(steppin1, HIGH);
    delayMicroseconds(pulsewidthMicros);
    digitalWrite(steppin1, LOW);
    delayMicroseconds(pulsewidthMicros);  
  }
}

void runStepper2(int direction, int numOfSteps, int pulsewidthMicros = 850) {
  digitalWrite(dirpin2, direction);
  for (int n = 0; n < numOfSteps; n++) {
    digitalWrite(steppin2, HIGH);
    delayMicroseconds(pulsewidthMicros);
    digitalWrite(steppin2, LOW);
    delayMicroseconds(pulsewidthMicros);  
  }
}

void runStepper3(int direction, int numOfSteps, int pulsewidthMicros = 850) {
  digitalWrite(dirpin3, direction);
  for (int n = 0; n < numOfSteps; n++) {
    digitalWrite(steppin3, HIGH);
    delayMicroseconds(pulsewidthMicros);
    digitalWrite(steppin3, LOW);
    delayMicroseconds(pulsewidthMicros);  
  }
}

void setup() {
  Serial.begin(9600);
  Serial.println("Testing stepper");
  
  pinMode(dirpin1, OUTPUT);
  pinMode(steppin1, OUTPUT);

  digitalWrite(dirpin1, LOW);
  digitalWrite(steppin1, LOW);

  pinMode(dirpin2, OUTPUT);
  pinMode(steppin2, OUTPUT);

  digitalWrite(dirpin2, LOW);
  digitalWrite(steppin2, LOW);

  pinMode(dirpin3, OUTPUT);
  pinMode(steppin3, OUTPUT);

  digitalWrite(dirpin3, LOW);
  digitalWrite(steppin3, LOW);
}

void loop() {
  //stepper1
 // Move forward 
// for (int i = 0; i < preDefinedDistance; i++) {
//   runStepper1(HIGH, 3200);
// }
//
// delay(1000); // 1 second pause

 // Move backward
 for (int i = 0; i < preDefinedDistance; i++) {
   runStepper1(LOW, 3200);
 }

 delay(1000); // 1 second pause 
}

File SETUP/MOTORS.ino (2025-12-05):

void initializeMotor(){
  pinMode(dirpin1, OUTPUT);
  pinMode(steppin1, OUTPUT);

  digitalWrite(dirpin1, LOW);
  digitalWrite(steppin1, LOW);

  pinMode(dirpin2, OUTPUT);
  pinMode(steppin2, OUTPUT);

  digitalWrite(dirpin2, LOW);
  digitalWrite(steppin2, LOW);

  pinMode(dirpin3, OUTPUT);
  pinMode(steppin3, OUTPUT);

  digitalWrite(dirpin3, LOW);
  digitalWrite(steppin3, LOW);
}

// ticker params is used to indicate the row for the message. It is default to 0
void screen(String scrollMessage, int ticker = 0) {
  int displayWidth = 16; 
  int scrollNum = scrollMessage.length() - displayWidth + 1;

  // Print the scrolling message to the second row
  lcd.clear();
  lcd.setCursor(0, ticker);
  lcd.print(scrollMessage);

  // Scroll the message to the left
  if (scrollNum > 0) {
    for (int i = 0; i < scrollNum; i++) {
      lcd.scrollDisplayLeft();
      delay(200); // Adjust delay for scrolling speed
    };
  }
  lcd.clear();
  lcd.setCursor(0, ticker);
  lcd.print(scrollMessage); 
  delay(1000); 
};

// This function take a string as an argument 
// lesser than 16 char and display it on the lcd screen
void fixScreen(String Message) {
  lcd.clear();
  lcd.setCursor(0, 0);
  lcd.print(Message);
}

// This function turns on the water spray
void turnOnWaterPump() {
  digitalWrite(pump1RelayPin, LOW);
  delay(1000);
  digitalWrite(pump1RelayPin, HIGH);
  delay(1000);
}
// This function turns on the Polish spray
void turnOnPump() {
  digitalWrite(pump2RelayPin, HIGH);
  delay(2000);
  digitalWrite(pump2RelayPin, LOW);
  delay(1000);
}

// This function power the buzzer after polishing
void alertUser(){
   digitalWrite(buzzerRelayPin, LOW); // Turn on buzzer to indicate end of cycle
   delay(2000); // Buzzer on for 2 seconds
   digitalWrite(buzzerRelayPin, HIGH); // Turn on buzzer to indicate end of cycle
}

// Function to run steppers
void runStepper1(int direction, int numOfSteps, int pulsewidthMicros = 35) {
  digitalWrite(dirpin1, direction);
  for (int n = 0; n < numOfSteps; n++) {
    digitalWrite(steppin1, HIGH);
    delayMicroseconds(pulsewidthMicros);
    digitalWrite(steppin1, LOW);
    delayMicroseconds(pulsewidthMicros);  
  }
}
void driveStepper1(){
    // Move forward
  for (int i = 0; i < preDefinedDistance; i++) {
    runStepper1(HIGH, 3200);
  }
  delay(1000); // 1 second pause

  // Move backward
  Serial.println("Moving Stepper 1 backward");
  for (int i = 0; i < preDefinedDistance; i++) {
    runStepper1(LOW, 3200);
  }
  delay(1000); // 1 second pause 
}

//
// Setting the numOfSteps to 48 to increase the speed
void runStepper2(int direction, int numOfSteps=800, int pulsewidthMicros = 10000000) {
  digitalWrite(dirpin2, direction);
  for (int n = 0; n < numOfSteps; n++) {
    digitalWrite(steppin2, HIGH);
    delayMicroseconds(pulsewidthMicros);
    digitalWrite(steppin2, LOW);
    delayMicroseconds(pulsewidthMicros);  
  }
}
void driveStepper2ClockWise(int x=800){
  // Move forward
  runStepper2(HIGH, x);
  delay(1000); // 1 second pause
}
void driveStepper2AntiClockWise(int x=800){
  // Move Backward
  runStepper2(LOW, x);
  delay(1000); // 1 second pause
}

void runStepper3(int direction, int numOfSteps, int pulsewidthMicros = 35) {
  digitalWrite(dirpin3, direction);
  for (int n = 0; n < numOfSteps; n++) {
    digitalWrite(steppin3, HIGH);
    delayMicroseconds(pulsewidthMicros);
    digitalWrite(steppin3, LOW);
    delayMicroseconds(pulsewidthMicros);  
  }
}
void driveStepper3(){
    // Move forward
  for (int i = 0; i < preDefinedDistance; i++) {
    runStepper3(LOW, 3200);
  }
  delay(1000); // 1 second pause

    // Move backward
  for (int i = 0; i < preDefinedDistance; i++) {
    runStepper3(HIGH, 3200);
  }
  delay(1000); // 1 second pause 
}


//ROTATION SEQUENCE FUNCTION
void setStep(int a, int b, int c, int d) {
  mcp.digitalWrite(A_0, a);
  mcp.digitalWrite(A_1, b);
  mcp.digitalWrite(A_2, c);
  mcp.digitalWrite(A_3, d);
  delayMicroseconds(STEP_DELAY);
}

void changePolishBrush(int cycles){
  // Calculate the total number of steps needed
  long totalSteps = ((long)cycles * STEPS_PER_REVOLUTION)/2;

  // Loop through all the steps
  for (long i = 0; i < totalSteps; i++) {    
    // Step 1: 1000
    setStep(HIGH, HIGH, LOW, LOW);
    // Step 2: 0100
    setStep(LOW, HIGH, HIGH, LOW);
    // Step 3: 0010
    setStep(LOW, LOW, HIGH, HIGH);
    // Step 4: 0001
    setStep(HIGH, LOW, LOW, HIGH);
  }
  setStep(LOW, LOW, LOW, LOW);
}

// Shoe cleaning functions
void cleanShoe() {
  // Clean routine
  // Move stepper 1 forward 

   // Drive shoe holder 
//   driveStepper2ClockWise();  
   
//   turnOnWaterPump();
   driveStepper1(); 

    // Drive shoe holder 
   driveStepper2AntiClockWise(); 

    // Clean left side of the shoe 
   driveStepper1(); 
   
   turnOnWaterPump();

   // Drive shoe holder 
   driveStepper2AntiClockWise();  

    // Clean top side of the shoe
   driveStepper1(); 
   
//   turnOnWaterPump();
   
   // Drive shoe holder
   driveStepper2AntiClockWise(805);  

   // Clean right side of the shoe
   driveStepper1();  
}
// Shoe polishing function
void polishShoe(){
  // Adjust this function to return the shoe to the start position
  driveStepper2ClockWise(1200);  // Drive shoe holder
  
  // polishing routine 
  
  // Activate pump for black polish on right side
  turnOnPump();     

  // Drive shoe holder
  driveStepper2ClockWise(650); 

  // Polish right side of shoe
  driveStepper3();  

  // Activate pump for black polish on top side 
  turnOnPump();

  
  driveStepper2ClockWise(400);  // Drive shoe holder

  driveStepper3();  // Polish top side of shoe

  // Drive shoe holder
  driveStepper2AntiClockWise(300);  

  // Activate pump for black polish
  turnOnPump();     

  // Drive shoe holder
  driveStepper2ClockWise(850);  

  // Drive polish brush and return to start
  driveStepper3();  

  // Drive shoe holder
  driveStepper2AntiClockWise();  

  // Drive shoe holder
  driveStepper2AntiClockWise();  
}

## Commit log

2025-10-19 added stepper script
2025-11-04 Moved the functions to MOTORS.ino file and optimize the engine
2025-11-13 changes made to mcp motors and setup files
2025-11-18 Adjusted Stepper 2 function to 1/16 step mode.
2025-11-25 Adjusted oldSketch-new switch case statement.
